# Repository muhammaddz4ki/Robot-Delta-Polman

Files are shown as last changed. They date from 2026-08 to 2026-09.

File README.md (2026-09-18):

# 3-DOF Parallel Delta Robot - Politeknik Manufaktur Bandung (POLMAN)








---

## Ringkasan Proyek (Abstract)

Repositori ini memuat rancang bangun dan implementasi terpadu sistem **3-DOF Parallel Delta Robot OS (v3.2)** yang dikembangkan di **Politeknik Manufaktur Bandung (POLMAN)**. Sistem ini mengintegrasikan kendali deterministik *low-level* berbasis mikrokontroler dengan ekosistem IoT nirkabel dan antarmuka web industri modern:

1. **Low-Level Motion Control (Arduino Mega 2560)**:
   - Perhitungan Kinematika Invers (*Inverse Kinematics*) berbasis model matematis Trossen Robotics.
   - Algoritma interpolasi koordinasi multi-axis (*Synchronized Multi-Axis Interpolation*) untuk lintasan 3D lurus dan mulus.
   - *Soft-Start Independent Power Homing* dengan peredam getaran beban inersia dan pengangkatan bertahap (*Smooth Staged Lift*).
   - Sistem keselamatan industri *Multi-Tier Emergency Stop (EMG)* dengan *Holding Torque* aktif dan proteksi hisap vakum.
   - Filter *software debounce* untuk sensor otomasi konveyor.
2. **IoT Gateway & Nirkabel (ESP32)**:
   - Mode ganda *Access Point (AP)* mandiri `DeltaRobot_Config` (`192.168.4.1`) dan *Station (STA)* Wi-Fi lokal.
   - Protokol mDNS lokal (`http://deltarobot.local`).
   - Jembatan komunikasi data *High-Speed UART (115200 baud)* dengan *CORS-enabled RESTful API JSON*.
   - Pembaruan program nirkabel *Over-The-Air (OTA) Web Firmware Update* (`/update`).
3. **Industrial Web Control Interface (React, Three.js, Node.js & MySQL)**:
   - Visualisasi *3D Digital Twin* interaktif dengan penanda target ruang kerja (*Ghost Target Markers*).
   - Penguji langkah per langkah (*Single-Step Sequencer*) untuk profiling Pick & Place yang aman.
   - Penyesuaian ketinggian instan (*Global Z-Offset Adjuster*).
   - Manajemen basis data resep / template koordinat kerja tanpa batas.
4. **Mechanical CAD 3D Models**:
   - Berkas CAD 3D presisi (.STEP & .STL) untuk lengan delta, bodi tripod, modul konveyor, dan beragam modul *end-effector* (vakum suction cup, servo gripper, soft gripper, dan laser).

---

## Arsitektur Sistem (System Architecture)

```mermaid
flowchart TD
    subgraph UserInterface["User Interface & Digital Twin Layer"]
        WebDashboard["React + Three.js Web Dashboard\n(3D Digital Twin, Step Sequencer, Jogging)"]
        DirectSerial["Serial Monitor / USB Terminal (115200 Baud)"]
    end

    subgraph ServerLayer["Application & Database Layer"]
        NodeServer["Node.js Express REST API\n(Port: 5000)"]
        MySQLDB[("MySQL Database\n(Users, Layouts, Recipes/Templates)")]
        NodeServer <--> MySQLDB
    end

    subgraph IoTGateway["IoT Gateway Layer (ESP32)"]
        ESP32Core["ESP32 Dual-Core SoC"]
        WiFiPortal["Dual Mode AP + STA Wi-Fi\n(mDNS: deltarobot.local)"]
        OTA["Web OTA Firmware Update (/update)"]
        RestBridge["REST API Bridge & CORS Handler"]
        ESP32Core --- WiFiPortal
        ESP32Core --- OTA
        ESP32Core --- RestBridge
    end

    subgraph EmbeddedController["Real-Time Motion & Safety Control (Arduino Mega 2560)"]
        MegaCore["ATmega2560 (16 MHz)"]
        IKEngine["Inverse Kinematics Engine\n(Trossen Robotics Model)"]
        HomingSync["Soft-Start Power Homing\n(3-Axis Zeroing Routine)"]
        SafetyManager["Emergency Stop (EMG)\n(Holding Torque & Vacuum Retention)"]
        EEPROMStore["EEPROM Memory Storage\n(Waypoints Backup)"]
        
        MegaCore --> IKEngine
        MegaCore --> HomingSync
        MegaCore --> SafetyManager
        MegaCore --> EEPROMStore
    end

    subgraph HardwareActuators["Mechanical & Actuator Layer"]
        MotorX["Stepper Motor X (Gear Ratio 3:1)"]
        MotorY["Stepper Motor Y (Gear Ratio 3:1)"]
        MotorZ["Stepper Motor Z (Gear Ratio 3:1)"]
        SuctionRelay["Relay Dinamo Vakum D12 (Active LOW)"]
        EmgSwitch["Saklar Darurat Fisik D31 (NC)"]
        LimitSwitches["Limit Switches (X, Y, Z Zeroing)"]
        ProximitySensors["Proximity Triggers (Debounced 30ms)"]
    end

    WebDashboard <-->|HTTP / REST API| NodeServer
    WebDashboard <-->|Direct Local REST / CORS| RestBridge
    NodeServer <-->|Serial / HTTP Bridge| ESP32Core
    DirectSerial <-->|UART0 (115200 Baud)| MegaCore
    RestBridge <-->|UART2 High-Speed (115200 Baud)| MegaCore

    IKEngine --> MotorX
    IKEngine --> MotorY
    IKEngine --> MotorZ
    MegaCore --> SuctionRelay
    EmgSwitch --> SafetyManager
    LimitSwitches --> HomingSync
    ProximitySensors --> MegaCore
```

---

## Parameter Kinematika & Ruang Kerja (Workspace Envelope)

Sistem mengadopsi formulasi matematis **3-DOF Parallel Delta Kinematics** dengan parameter dimensi terkalibrasi:

$$\begin{aligned}
\text{Radius Base } (f) &= 80.0\text{ mm} \\
\text{Panjang Lengan Biceps } (r_f) &= 130.0\text{ mm} \\
\text{Panjang Lengan Forearm } (r_e) &= 300.0\text{ mm} \\
\text{Radius End-Effector } (e) &= 40.0\text{ mm} \\
\text{Planetary Gear Ratio (Hanpose PG5.18)} &= 5.18:1 \\
\text{Sudut Arm saat Homing } (\theta_{\text{home}}) &= -36.0^\circ
\end{aligned}$$

### Amplop Ruang Kerja (Workspace Limits)
* **Batas Jangkauan Horizontal ($XY$):** Radius maksimal $150.0\text{ mm}$ ($\sqrt{X^2 + Y^2} \le 150.0\text{ mm}$).
* **Batas Jangkauan Vertikal ($Z$):** $Z_{\text{maks}} = -50.0\text{ mm}$ hingga $Z_{\text{min}} = -400.0\text{ mm}$ (Batas fisik absolut).
* **Margin Keselamatan Kerja ($Z_{\text{safe}}$):** $Z_{\text{safe\_min}} = -392.0\text{ mm}$ (Margin $8.0\text{ mm}$ dari $Z_{\text{min}}$ demi mencegah *stall* motor dan singularitas kinematika pada sudut lengan ekstrem).
* **Posisi Default Standby (Home):** $X = 0.0\text{ mm},\; Y = 0.0\text{ mm},\; Z = -200.0\text{ mm}$.

---

## Pemetaan Pin Perangkat Keras (Hardware Pinout)

### 1. Mikrokontroler Utama (Arduino Mega 2560)
| Kategori | Nama Sinyal | Pin Arduino Mega | Mode Pin | Keterangan / Konfigurasi |
|---|---|---|---|---|
| **Motor Stepper X** | STEP / DIR | Pin `7` / Pin `6` | OUTPUT | Hanpose PG5.18 (Ratio 5.18:1, 2.878 steps/deg) |
| **Motor Stepper Y** | STEP / DIR | Pin `44` / Pin `42` | OUTPUT | Hanpose PG5.18 (Ratio 5.18:1, 2.878 steps/deg) |
| **Motor Stepper Z** | STEP / DIR | Pin `5` / Pin `4` | OUTPUT | Hanpose PG5.18 (Ratio 5.18:1, 2.878 steps/deg) |
| **Relay Dinamo Vakum** | Suction Signal | Pin `12` | OUTPUT | Active LOW (LOW = ON, HIGH = OFF) |
| **Emergency Switch** | EMG Button | Pin `31` | INPUT_PULLUP | Active HIGH (NC Switch opens on press) |
| **Limit Switch X** | Limit Sensor | Pin `9` | INPUT_PULLUP | Active LOW saat tertekan |
| **Limit Switch Y** | Limit Sensor | Pin `11` | INPUT_PULLUP | Active LOW saat tertekan |
| **Limit Switch Z** | Limit Sensor | Pin `41` | INPUT_PULLUP | Active LOW saat tertekan |
| **Proximity Sensor 0** | Trigger RUN | Pin `2` | INPUT_PULLUP | Filter Debounce 30ms (Auto Run EEPROM) |
| **Proximity Sensor 1** | Trigger STARTA | Pin `53` | INPUT_PULLUP | Filter Debounce 30ms (Auto Profil A) |
| **Proximity Sensor 2** | Trigger STARTB | Pin `51` | INPUT_PULLUP | Filter Debounce 30ms (Auto Profil B) |
| **UART Bridge (ESP32)** | RX2 / TX2 | Pin `17` (RX2) / Pin `16` (TX2) | SERIAL2 | Kecepatan Tinggi: `115200 bps` |
| **USB Monitor (PC)** | USB CDC | Pin `0` (RX0) / Pin `1` (TX0) | SERIAL | Kecepatan: `115200 bps` |

### 2. IoT Gateway (ESP32 Dev Module)
| Antarmuka | Pin ESP32 | Terhubung Ke | Deskripsi |
|---|---|---|---|
| **UART2 RX** | GPIO `16` | Mega Pin `16` (TX2) | Menerima status koordinat & log Mega |
| **UART2 TX** | GPIO `17` | Mega Pin `17` (RX2) | Mengirim perintah gerak & kontrol ke Mega |

---

## Protokol Komunikasi & Serial Commands

Komunikasi data serial berjalan pada baudrate **`115200 bps`** dengan terminasi `Newline (\n)`.

| Perintah | Contoh Format | Deskripsi & Respons Sistem |
|---|---|---|
| **Gerak Koordinat** | `0 0 -250` | Menggerakkan end-effector ke target $(X, Y, Z)$ secara terkoordinasi |
| `HOME` | `HOME` | Menjalankan *Smooth Staged Homing* (Lifting $\rightarrow$ Centering $\rightarrow$ Zeroing) |
| `TIUP` / `AMBIL` | `TIUP` | Mengaktifkan pompa 1 untuk meniup (mencengkeram benda) dan menahan |
| `HISAP` / `LEPAS` | `HISAP` | Mengaktifkan pompa 2 untuk menghisap (melepaskan benda) |
| `SET_GRIP_TIME [t1] [t2]` | `SET_GRIP_TIME 4000 1000` | Mengatur durasi waktu tiup & hisap (1000 - 10000 ms / 1 - 10 detik) |
| `SET_GRIP_SPEED [p1] [p2]` | `SET_GRIP_SPEED 255 255` | Mengatur kecepatan PWM pompa 1 (Tiup) dan pompa 2 (Hisap) (0-255) |
| `STOP_PUMP` / `GRIP_STOP` | `STOP_PUMP` | Mematikan kedua pompa L298N (Kondisi Netral) |
| `EMG` / `STOP` | `EMG` | Toggle mode darurat (Motor mengunci posisi, pompa mati seketika demi keselamatan) |
| `RESET` | `RESET` | Melepas status darurat dan mengembalikan robot ke kondisi siap operasi |
| `STARTA` | `STARTA` | Menjalankan sekuensi otomatis *Pick & Place* Profil A |
| `STARTB` | `STARTB` | Menjalankan sekuensi otomatis *Pick & Place* Profil B |
| `SET_A_PICK X Y Z`| `SET_A_PICK 20 -30 -280` | Memperbarui titik ambil Profil A secara dinamis dari web |
| `SET_A_DROP X Y Z`| `SET_A_DROP 20 120 -320` | Memperbarui titik letak Profil A secara dinamis dari web |
| `SET_B_PICK X Y Z`| `SET_B_PICK -55 -40 -280` | Memperbarui titik ambil Profil B secara dinamis dari web |
| `SET_B_DROP X Y Z`| `SET_B_DROP -80 110 -320` | Memperbarui titik letak Profil B secara dinamis dari web |
| `SET_SPEED [val]` | `SET_SPEED 700` | Mengatur batas kecepatan maksimum motor stepper |
| `SET_ACCEL [val]` | `SET_ACCEL 350` | Mengatur akselerasi gerak motor stepper |
| `STATUS` | `STATUS` | Mengembalikan status koordinat aktual, status sensor, dan mode darurat |
| `SAVE` | `SAVE` | Menyimpan koordinat aktual ke EEPROM (Maksimal 10 titik) |
| `RUN` | `RUN` | Mengeksekusi pergerakan sekuensial seluruh waypoint di EEPROM |
| `CLEAR` | `CLEAR` | Menghapus seluruh memori titik koordinat di EEPROM |

---

## Antarmuka RESTful API (ESP32 & Node.js Backend)

### ESP32 Micro-Endpoints (Port `80` / `deltarobot.local`)
- `GET /` : Built-in Web Portal untuk pemindaian dan konfigurasi Wi-Fi.
- `GET /status` : Mengembalikan status koneksi Wi-Fi, IP, SSID, dan log UART terakhir.
- `GET /cmd?val=...` : Eksekusi perintah kontrol langsung via URL query.
- `POST /cmd` : Eksekusi perintah kontrol via JSON body (`{"command": "HOME"}`).
- `GET /scan` : Pemindaian daftar jaringan Wi-Fi 2.4 GHz di sekitar ESP32.
- `GET/POST /update` : Web portal untuk upload firmware nirkabel (*Over-The-Air*).

### Node.js Express Endpoints (Port `5000`)
- `POST /api/login` : Autentikasi operator / admin menggunakan JWT.
- `POST /api/command` : Dispatch perintah gerak ke hardware / simulator.
- `GET/POST /api/layout` : Manajemen konfigurasi tata letak visualizer 3D.
- `GET/POST/DELETE /api/templates` : Manajemen template resep koordinat Pick & Place di basis data MySQL.

---

## Struktur Direktori Proyek

```text
Robot-Delta/
├── .gitignore                   # Konfigurasi ignoransi berkas Git
├── package.json                 # Konfigurasi Unified Workspace Runner (1 Terminal)
├── README.md                    # Dokumentasi komprehensif proyek (Dokumen ini)
│
├── firmware/                    # Firmware Mikrokontroler (Standar Arduino IDE)
│   ├── DeltaRobot_Mega/
│   │   └── DeltaRobot_Mega.ino  # Firmware utama Arduino Mega 2560 (IK, Homing & Motion Control)
│   └── DeltaRobot_ESP32/
│       └── DeltaRobot_ESP32.ino # Firmware IoT Gateway ESP32 (Wi-Fi, REST API, OTA Update)
│
├── Backend/                     # Layanan Backend Node.js & Express
│   ├── .env.example             # Contoh konfigurasi environment backend
│   ├── package.json             # Dependensi backend (Express, MySQL2, JWT, CORS)
│   ├── server.js                # Entry point REST API Server
│   └── setup.sql                # Skema inisialisasi basis data MySQL
│
├── frontend/                    # Web Control Interface (React + Three.js + Vite)
│   ├── .env.example             # Contoh konfigurasi environment frontend
│   ├── package.json             # Dependensi frontend & UI libraries
│   ├── vite.config.js           # Konfigurasi bundler Vite
│   ├── index.html               # Entry point HTML
│   └── src/                     # Source code aplikasi React
│       ├── pages/               # Dashboard, Landing Page, Login, Visualizer
│       ├── components/          # 3D Canvas Twin, Coordinate Markers, Telemetry Cards
│       └── ...
│
├── hardware/                    # Desain CAD Mekanik & Manufaktur 3D
│   ├── Delta X 1 - v2.STEP       # Master assembly CAD model
│   ├── TripodBase.stl           # Base mounting tripod 3D model
│   ├── Conveyor-X/              # Desain modular konveyor pendukung
│   ├── Slider-X/                # Desain modular slider linear
│   ├── Delta-X-Robot/           # CAD komponen lengan dan bodi delta
│   └── Delta-X-End-Effectors/   # Beragam modul aktuator (Vacuum, Gripper, Soft, Laser)
│
└── docs/                        # Dokumentasi teknis terpusat
    └── ARCHITECTURE.md          # Spesifikasi arsitektur & pinout perangkat keras
```

---

## Panduan Instalasi & Pengoperasian

### 1. Pemrograman Firmware Mikrokontroler
1. **Arduino Mega 2560:**
   - Buka `firmware/DeltaRobot_Mega/DeltaRobot_Mega.ino` di **Arduino IDE**.
   - Pasang library: `AccelStepper` dan `EEPROM`.
   - Pilih Board: **Arduino Mega or Mega 2560** $\rightarrow$ Prosesor: **ATmega2560 (Mega 2560)**.
   - Sambungkan kabel USB dan klik **Upload**.
2. **ESP32 IoT Gateway:**
   - Buka `firmware/DeltaRobot_ESP32/DeltaRobot_ESP32.ino` di **Arduino IDE**.
   - Pilih Board: **ESP32 Dev Module** $\rightarrow$ klik **Upload**.
   - Hubungkan laptop ke Wi-Fi `DeltaRobot_Config` (Password: `12345678`), buka browser pada `http://192.168.4.1` atau `http://deltarobot.local` untuk konfigurasi jaringan.

### 2. Konfigurasi Web App (Backend + Frontend)

#### A. Persiapan Lingkungan & Dependensi
1. Pastikan service **MySQL** telah aktif (misal via XAMPP).
2. Di root folder `d:\Robot Delta`, install seluruh dependensi sekaligus dengan **satu perintah**:
   ```bash
   npm run install:all
   ```
   *(Perintah ini akan menginstal dependensi root runner, Backend Node.js, dan Frontend Vite secara otomatis).*

#### B. Menjalankan Sistem (Unified Runner - Cukup 1 Terminal)
Cukup buka **1 terminal** di root folder `d:\Robot Delta` dan jalankan:
```bash
npm run dev
```
> **Output Terminal:**
> * `[BACKEND]` (Biru)  : Node.js Express REST API aktif di `http://localhost:5000`
> * `[FRONTEND]` (Cyan) : Vite React Dashboard aktif di `http://localhost:5173`

Buka peramban pada **`http://localhost:5173`** untuk mengakses antarmuka kontrol.

#### C. Menjalankan Secara Manual (Opsi Terminal Terpisah)
Jika Anda ingin menjalankan layanan secara terpisah di terminal independen:
* **Hanya Backend**: `npm run dev:backend` (atau `cd Backend && npm run dev`)
* **Hanya Frontend**: `npm run dev:frontend` (atau `cd frontend && npm run dev`)
* **Build Produksi Frontend**: `npm run build`

---

## Pengembang & Pembimbing Akademik

* **Institusi:** Politeknik Manufaktur Bandung (POLMAN Bandung)
* **Program Studi:** Teknologi Rekayasa Informatika Industri
* **Pengembang Utama:** [Muhammad Dzaki](https://github.com/muhammaddz4ki)

---

## Lisensi (License)

Proyek ini didistribusikan di bawah lisensi terbuka untuk keperluan akademik, riset, dan pengembangan teknologi otomasi manufaktur.

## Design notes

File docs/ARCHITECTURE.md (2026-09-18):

# Arsitektur & Spesifikasi Sistem Delta Robot

Dokumen ini menjelaskan struktur arsitektur perangkat keras, firmware, antarmuka komunikasi, backend, dan frontend sistem kontrol Robot Delta Polman.

---

## 1. Ikhtisar Arsitektur Sistem

Sistem Robot Delta menggunakan arsitektur modular berlapis:

```mermaid
graph TD
    subgraph Pengguna & Operator
        Browser[Dashboard Web React + Three.js]
    end

    subgraph Server & Cloud
        Backend[Backend Node.js + Express]
        MySQL[(Database MySQL)]
    end

    subgraph Jaringan & Komunikasi
        WiFi[Koneksi Wi-Fi 2.4 GHz]
        USB[Web Serial API / USB COM]
    end

    subgraph Kontroler Mikrokontroler
        ESP32[ESP32 Wi-Fi & REST Gateway]
        Mega[Arduino Mega 2560 R3]
    end

    subgraph Aktuator & Sensor
        Steppers[3x Stepper NEMA 23 + Driver TB6600]
        Gripper[Vakum Solenoid / Relay Gripper]
        Proximity[3x Sensor Proximity Induktif]
    end

    Browser <-->|HTTP REST / WebSocket| Backend
    Backend <--> MySQL
    Browser <-->|HTTP REST /status, /cmd| ESP32
    Browser <-->|Direct Web Serial| Mega
    ESP32 <-->|UART Serial2 @ 115200 bps| Mega
    Mega --> Steppers
    Mega --> Gripper
    Mega <-- Proximity
```

---

## 2. Struktur Direktori Repositori

```text
Robot-Delta/
├── firmware/                      # Firmware mikrokontroler
│   ├── DeltaRobot_Mega/
│   │   └── DeltaRobot_Mega.ino    # Firmware kendali kinematika invers & stepper Mega 2560
│   └── DeltaRobot_ESP32/
│       └── DeltaRobot_ESP32.ino   # Firmware Wi-Fi Web Server & bridge UART ESP32
│
├── Backend/                       # Layanan REST API & database Node.js Express
│   ├── .env.example
│   ├── package.json
│   ├── server.js                  # Server utama (Port 5000)
│   └── setup.sql                  # Skema database MySQL
│
├── frontend/                      # Aplikasi antarmuka web (React + Vite + Three.js)
│   ├── public/                    # Model STL Robot & Logo SVG
│   ├── src/                       # Komponen UI, Visualisasi Digital Twin, Pages
│   ├── package.json
│   └── vite.config.js
│
├── hardware/                      # Desain mekanikal CAD & 3D Printing STL
│   ├── Conveyor-X/
│   ├── Delta-X-End-Effectors/
│   ├── Delta-X-Robot/
│   ├── Slider-X/
│   └── Delta X 1 - v2.STEP
│
├── docs/                          # Dokumentasi teknis terpusat
│   └── ARCHITECTURE.md
│
├── package.json                   # Root orchestrator runner (concurrently)
└── README.md                      # Dokumentasi umum proyek
```

---

## 3. Alokasi Pinout Perangkat Keras (Arduino Mega 2560)

| Komponen | Pin Arduino Mega | Keterangan |
| :--- | :--- | :--- |
| **Stepper Motor 1** | Pin 3 (STEP), Pin 4 (DIR) | Sumbu A (Lengan 1) |
| **Stepper Motor 2** | Pin 5 (STEP), Pin 6 (DIR) | Sumbu B (Lengan 2) |
| **Stepper Motor 3** | Pin 7 (STEP), Pin 8 (DIR) | Sumbu C (Lengan 3) |
| **Limit Switch / Home**| Pin 18, 19, 20 (Interrupt) | Switch Homing Sumbu 1, 2, 3 |
| **Sensor Proximity A** | Pin 53 | Deteksi benda kerja di Pick Point A |
| **Sensor Proximity B** | Pin 51 | Deteksi benda kerja di Pick Point B |
| **Sensor Proximity 3** | Pin 2 | Cadangan sensor proximity jalur conveyor |
| **Relay / Pompa Vakum**| Pin 12 | Aktuator Suction Cup (Grip & Release) |
| **Tombol Emergency** | Pin 21 (External Interrupt)| Interlock Darurat Perangkat Keras |
| **Komunikasi UART2** | Pin 16 (TX2), Pin 17 (RX2) | Terhubung ke ESP32 RX2/TX2 (115200 bps)|

---

## 4. Mode Operasi Standar Industri

Sistem mengadopsi standar keselamatan mesin industri:

1. **Mode MANUAL (Setup / Maintenance)**:
   - Pengguna bebas melakukan Jogging manual pada sumbu X, Y, dan Z.
   - Sensor proximity dinonaktifkan untuk mencegah pemicuan siklus otomatis tak terduga saat kalibrasi atau perawatan mekanik.
   - Akses penuh ke pengubahan parameter kecepatan, akselerasi, dan template koordinat.

2. **Mode AUTO (Line Production)**:
   - Tombol jogging dan konfigurasi dinonaktifkan demi keselamatan operator.
   - Sensor proximity membaca kedatangan part di konveyor secara aktif.
   - Robot secara otonom menjalankan siklus Pick & Place sesuai koordinat template yang tersimpan di EEPROM.

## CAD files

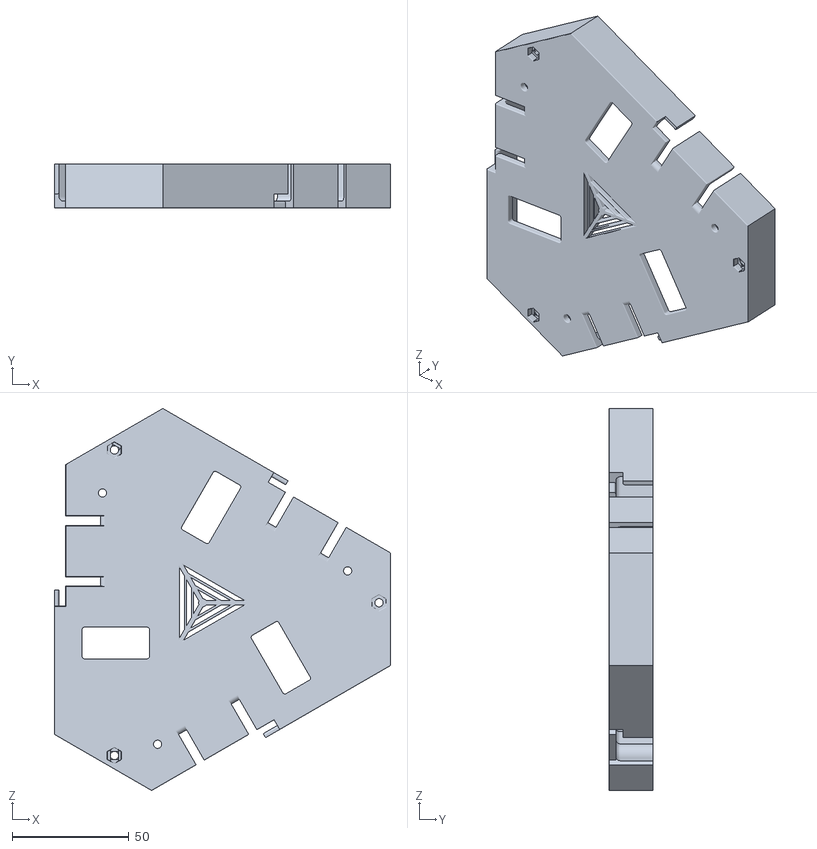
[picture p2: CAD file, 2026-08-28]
hardware/Delta-X-Robot/Delta X 1 - MainBox V2-1.STL
143.8 x 19.0 x 163.3

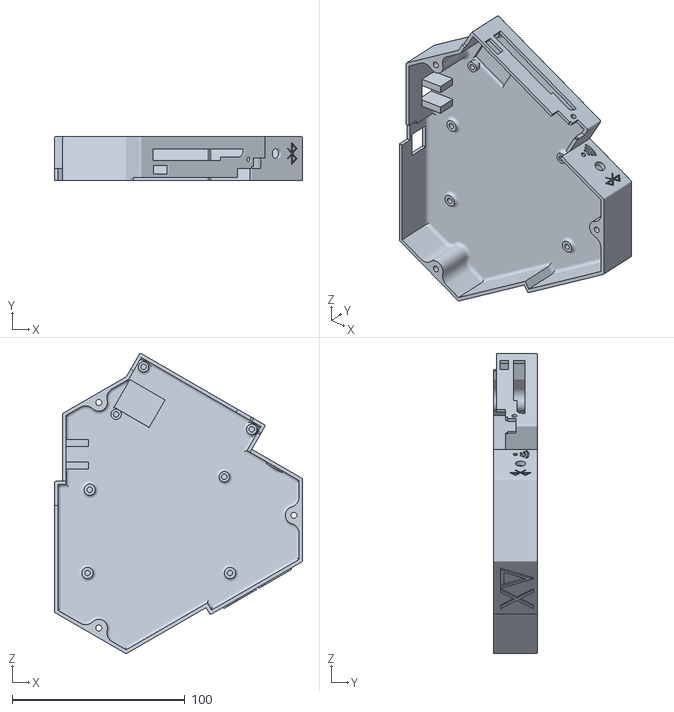
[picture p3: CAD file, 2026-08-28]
hardware/Delta-X-Robot/Delta X 1 - MainBoxLid V2-1.STL
143.8 x 25.8 x 173.8

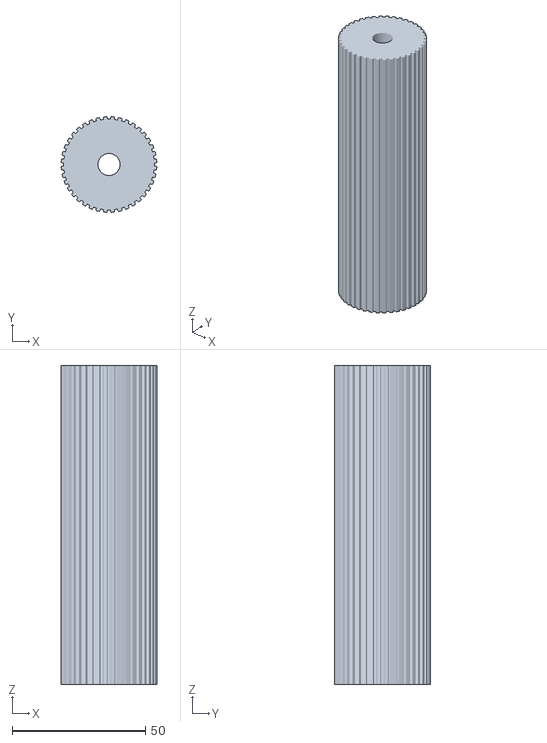
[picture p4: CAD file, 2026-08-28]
hardware/Conveyor-X/Roller.STL
36.0 x 36.0 x 119.8

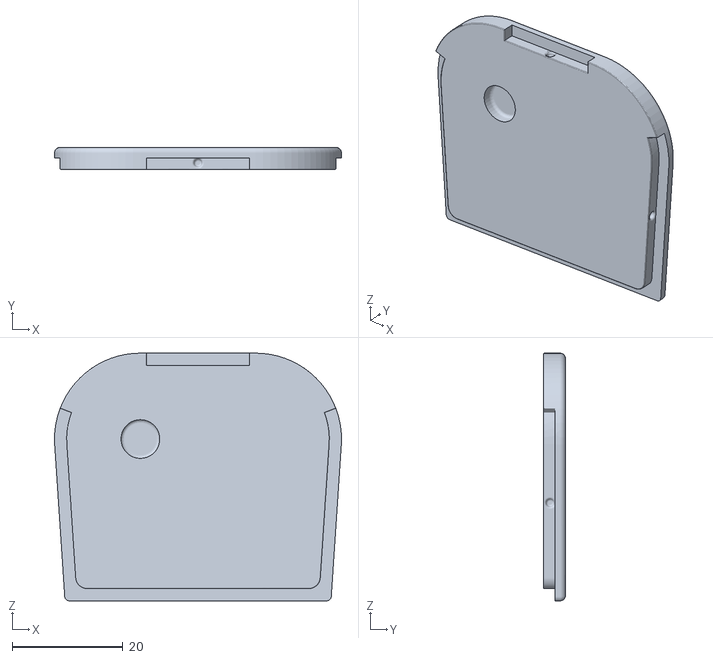
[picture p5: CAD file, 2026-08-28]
hardware/Delta-X-End-Effectors/Axis4 - Gripper/Axis4 Gripper Lib.STL
51.8 x 4.00 x 44.7

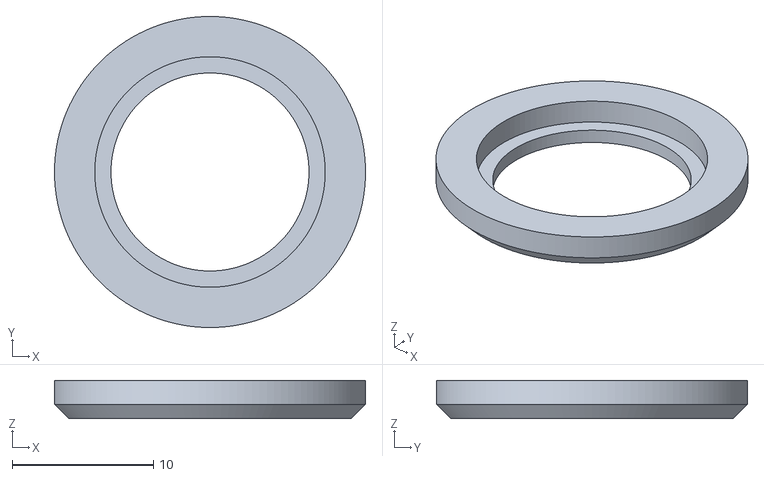
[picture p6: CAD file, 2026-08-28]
hardware/Delta-X-End-Effectors/Axis4 - Gripper/v2/Bearing.STL
22.0 x 22.0 x 2.70

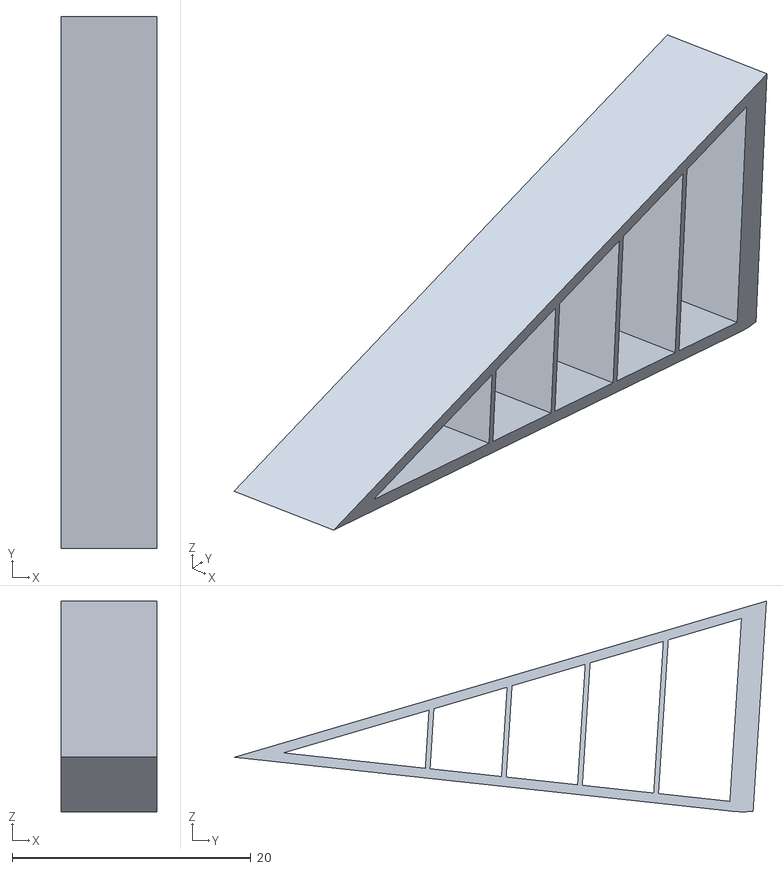
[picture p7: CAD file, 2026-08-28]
hardware/Delta-X-End-Effectors/Flexible Gripper/Flexible Gripper _ 2 _plastic.STL
8.00 x 44.5 x 17.7

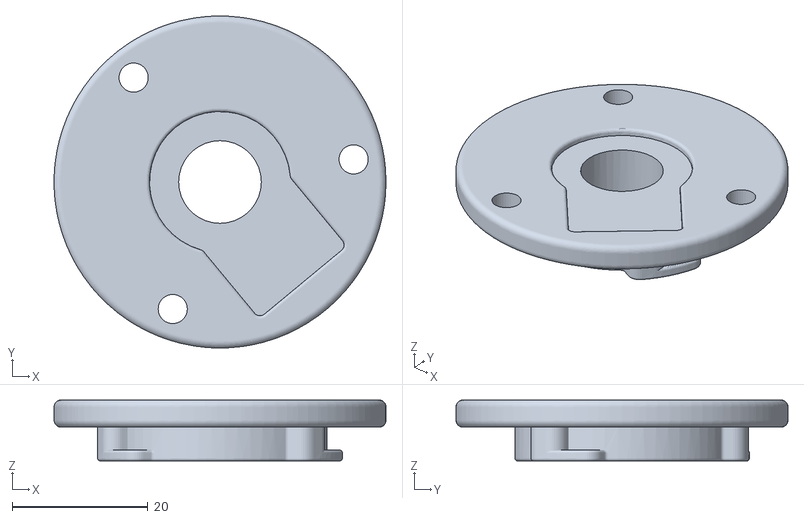
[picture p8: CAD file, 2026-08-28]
hardware/Delta-X-End-Effectors/v2/Step-file/Pen Holder 2.STL
49.0 x 49.0 x 9.00

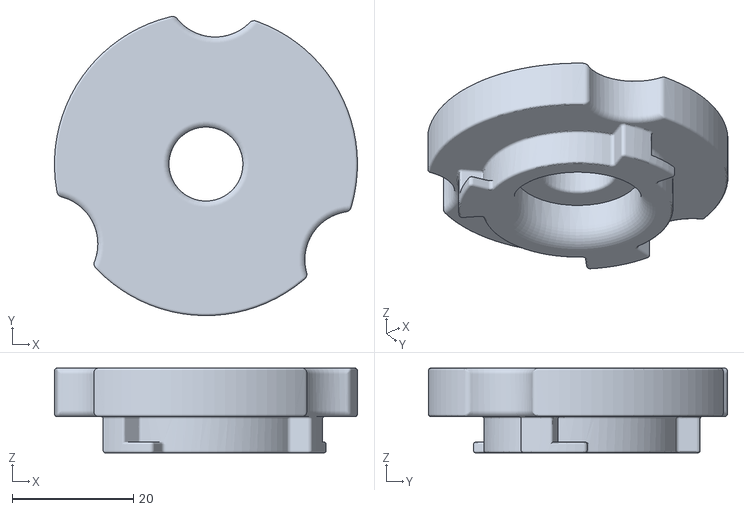
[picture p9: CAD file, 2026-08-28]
hardware/Delta-X-End-Effectors/Vacuum/Vaccum Jig.STL
50.0 x 49.4 x 14.0

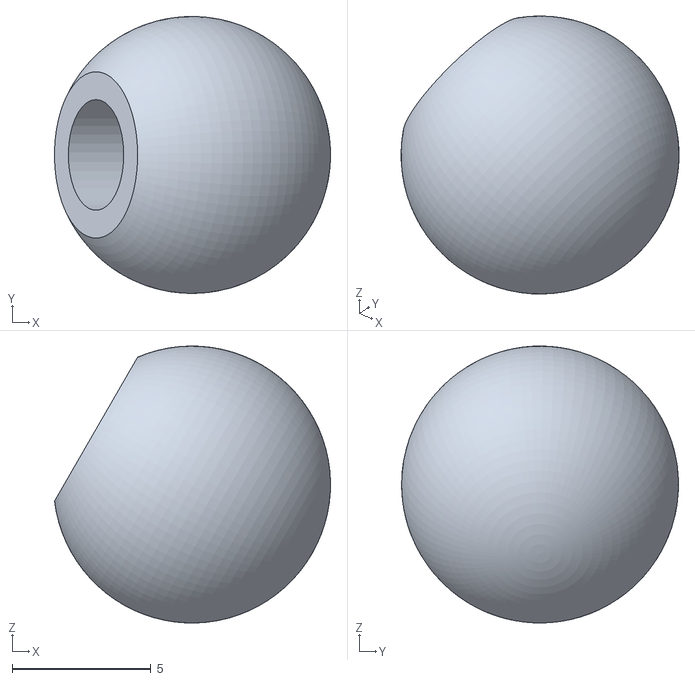
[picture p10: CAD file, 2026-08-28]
hardware/Delta-X-Robot/Delta X 1 - MovingBase-4 Joint Ball-4.STL
9.96 x 10.00 x 10.00

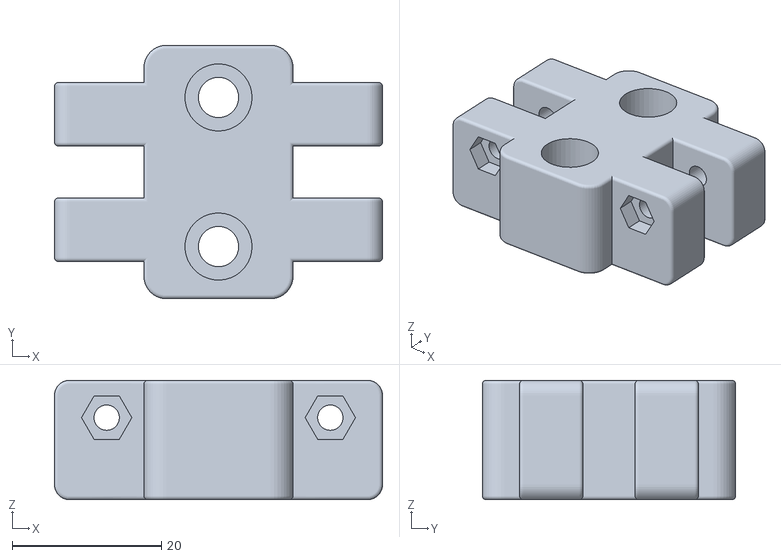
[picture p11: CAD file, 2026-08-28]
hardware/Slider-X/BeltKeeper.STL
44.0 x 34.0 x 16.0

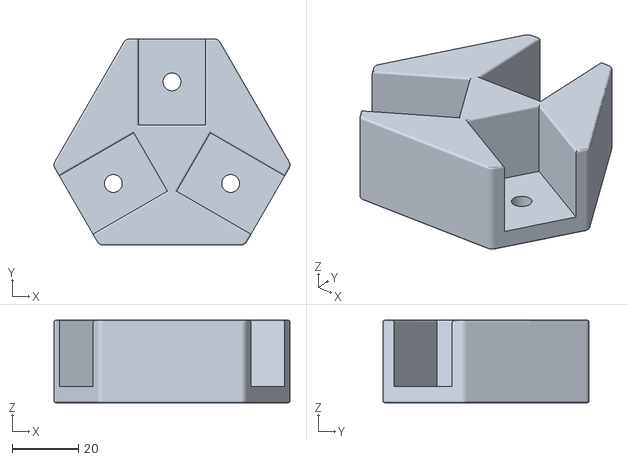
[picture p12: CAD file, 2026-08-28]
hardware/TripodBase.stl
71.4 x 62.4 x 25.0

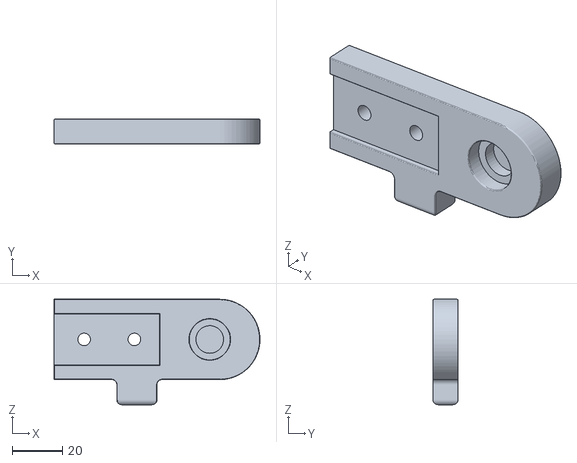
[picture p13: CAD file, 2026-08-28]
hardware/Conveyor-X/RollerAxisHolder.STL
82.0 x 10.0 x 42.0

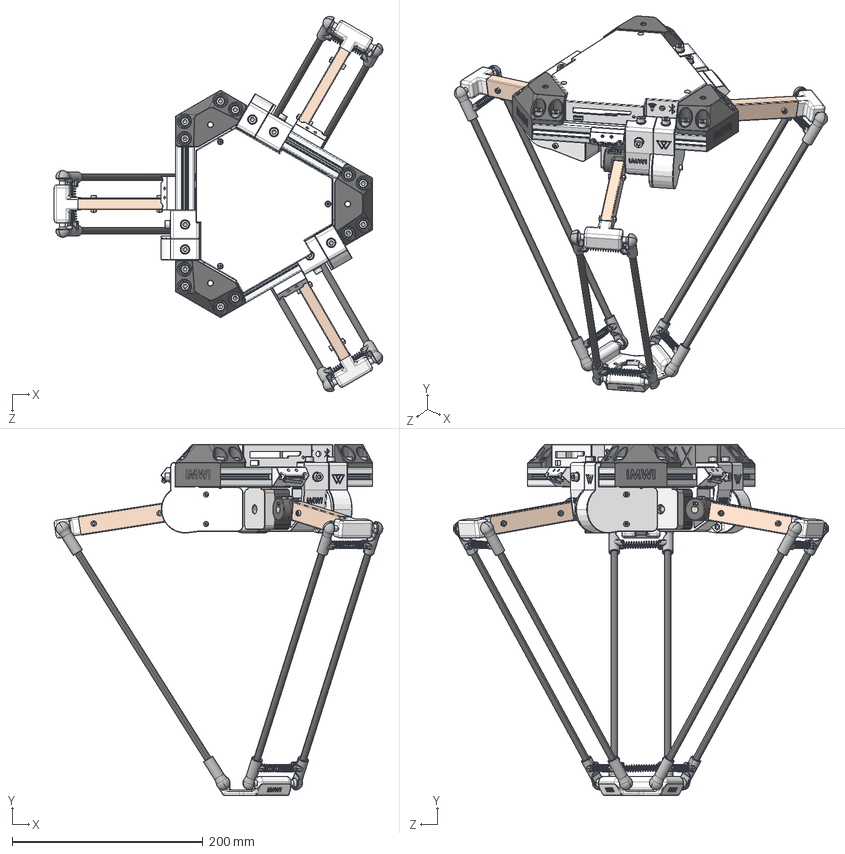
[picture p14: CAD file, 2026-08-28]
hardware/Delta X 1 - v2.STEP
345.0 x 368.5 x 394.1 mm
2020_Alu profile_Default<As Machined> x 3
Stepper Servo x 3
GearboxBody V2 x 3
Alu plate increase hardness x 3
Cross M3x10 bolt_Cross M3x10 bolt x 6
M3 Nut_M3 Nut x 21
Bearing 8_16 x 6
Bearing 5_16 x 3
BeltTensioner x 3
BeltTensioner2 x 3
BeltTensionerBase-v1 x 3
Cross M3x16 bolt_Cross M3x10 bolt x 3
M3x25 bolt_M3x8 bolt x 3
M3x12 bolt_M3x8 bolt x 3
M3x20 bolt_M3x8 bolt x 3
ring 8mm x 6
GearboxLid V2 x 3
M3x30 bolt_M3x8 bolt x 6
Frame connector x 3
M5 Washer_M5 Washer x 21
M5x10 bolt_M5x10 bolt x 21
T Slot Nut_______ _______ 6__ _5 x 21
inox8 x 3
Shoulder x 3
Nut m3 x 6
M3x8 bolt_M3x8 bolt x 6
Nhomtay_Default<As Machined> x 3
ElbowV2 x 3
M4x60 thread_M4x60 thread x 6
Joint Ball x 12
vongdem3m x 12
M3x15 bolt_M3x8 bolt x 6
MainBox V2
MainBoxLid V2
Endstop Limit Switch x 3
EndstopHolder x 3
M3x10 bolt_M3x8 bolt x 9
M3 T Slot Nut_______ _______ 6__ _5 x 6
GearBoxSprings x 3
GT2_60T_8 x 3
GT2_20T_5_____________1 x 3
Belt1-1^Delta X 1 x 3
M3x40 bolt_M3x8 bolt x 3
Base-EndEffecterV2
cacbon x 6
RodEnd-1-V2 x 12
Spring Stick x 12
ArmSpring x 6

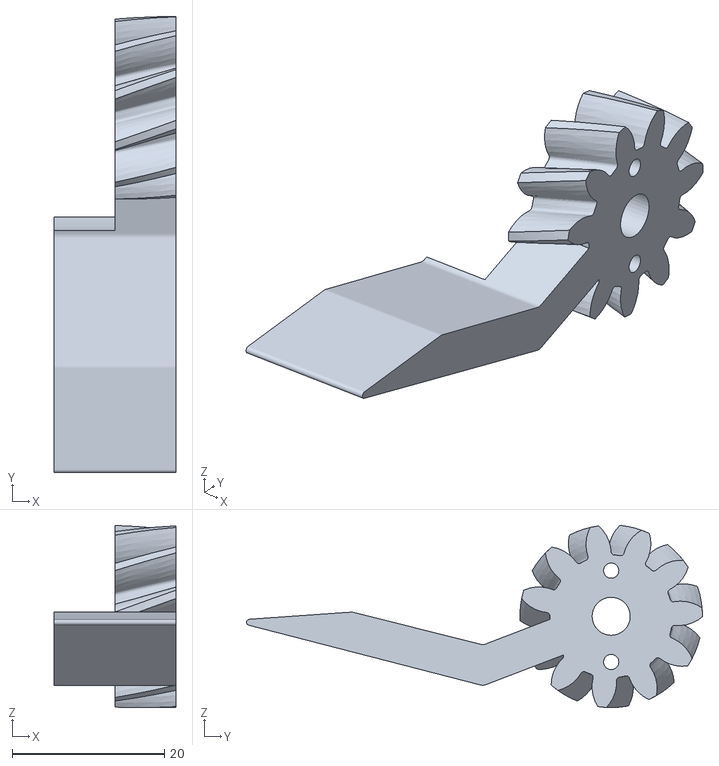
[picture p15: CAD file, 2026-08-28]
hardware/Delta-X-End-Effectors/Axis4 - Gripper/LH Helical gear 1.75M 11T.STL
16.0 x 59.9 x 23.9

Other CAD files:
hardware/Delta-X-End-Effectors/Axis4 - Gripper/v2/VaccumBase-SV.STL
hardware/Delta-X-End-Effectors/Flexible Gripper/Flexible Gripper Lib.STL
hardware/Delta-X-End-Effectors/v2/Step-file/SoftGripper.STEP
hardware/Delta-X-End-Effectors/Vacuum/LidVaccumBox.STL
hardware/Conveyor-X/Adjust-Tool.STL
hardware/Conveyor-X/ConveyorGearBox-Body.STL
hardware/Conveyor-X/ConveyorGearBox-Lid.STL
hardware/Conveyor-X/RollerAxisHolder-Mirror.STL
hardware/Conveyor-X/StepperWedge.STL
hardware/Delta-X-End-Effectors/Axis4 - Gripper/Axis4 Gripper Box.STL
hardware/Delta-X-End-Effectors/Axis4 - Gripper/Axis4 Gripper Top.STL
hardware/Delta-X-End-Effectors/Axis4 - Gripper/Axis4 Gripper.STEP
hardware/Delta-X-End-Effectors/Axis4 - Gripper/RH Helical gear 1.75M 11T.STL
hardware/Delta-X-End-Effectors/Axis4 - Gripper/v2/Axis4-Vacuum-Bottom-SV.stl
hardware/Delta-X-End-Effectors/Axis4 - Gripper/v2/Base-1.stl
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

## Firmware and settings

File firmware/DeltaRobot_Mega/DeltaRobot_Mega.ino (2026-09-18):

// =================================================================
// DELTA ROBOT v3.2 - POLMAN BANDUNG / MAJALENGKA (FULL INTEGRATION)
// HOMING = POWER MODE (manual, tanpa AccelStepper, independent timing per motor)
// Gerakan koordinat (XYZ, STARTA, STARTB, RUN) = AccelStepper Coordinated Move
// IK: standar Trossen Robotics + HOMING_THETA_DEG agar arah Y simetris
// END-EFFECTOR: SOFT ROBOTIC GRIPPER VIA DRIVER L298N (DUAL PUMP TIUP & HISAP)
// L298N PINOUT: IN1=23, IN2=25, IN3=27, IN4=29, ENA=45 (PWM), ENB=12 (PWM SERVOS)
// LOGIKA: TIUP = AMBIL BARANG | HISAP = LEPAS BARANG (DENGAN KONTROL WAKTU / TIMING)

#include <AccelStepper.h>
#include <EEPROM.h>

#define motorInterfaceType 1

// ===== PIN MOTOR =====
const int stepPinX = 7;  const int dirPinX = 6;
const int stepPinY = 44; const int dirPinY = 42;
const int stepPinZ = 5;  const int dirPinZ = 4;

// ===== PIN LIMIT SWITCH =====
const int limitX = 9;
const int limitY = 11;
const int limitZ = 41;

// ===== PIN PROXIMITY =====
const int proximityPin  = 2;
const int proximityPin1 = 53;
const int proximityPin2 = 51;
const int PROX_ACTIVE_STATE = HIGH;

// ===== PIN L298N DUAL PUMP CONTROLLER (SOFT GRIPPER) =====
// Pompa 1 = TIUP (Ambil Barang / Grip Inflate)
// Pompa 2 = HISAP (Lepas Barang / Release Deflate)
const int pump1_IN1 = 23; // Pompa 1 Arah A
const int pump1_IN2 = 25; // Pompa 1 Arah B
const int pump2_IN3 = 27; // Pompa 2 Arah A
const int pump2_IN4 = 29; // Pompa 2 Arah B
const int pump1_ENA = 45; // Speed Pompa 1 (PWM P45)
const int pump2_ENB = 12; // Speed Pompa 2 (PWM SERVOS D12)

// Parameter Soft Gripper
int pump1_Speed = 255; // PWM 0 - 255
int pump2_Speed = 255; // PWM 0 - 255
unsigned long gripTiupDuration   = 1200; // ms (Waktu tiup untuk ambil barang)
unsigned long gripHisapDuration  = 1000; // ms (Waktu hisap untuk lepas barang)
unsigned long gripExpandDuration = 800;  // ms (Waktu hisap sebentar untuk mengembang/membuka cakar sebelum ambil barang)
bool gripHoldContinuous = true;          // true = Tiup 100% penuh terus menerus selama membawa barang | false = Mode hemat daya 55%
String gripState = "NETRAL"; // "NETRAL", "TIUP", "HISAP"

const int emgPin   = 31;  // Emergency Switch Pin D31 (INPUT_PULLUP)
const int EMG_ACTIVE_STATE = HIGH; // Active HIGH saat tombol ditekan (NC switch)

bool isHardwareEmg = false;
bool isSoftwareEmg = false;

bool isEmgActive() {
  return isHardwareEmg || isSoftwareEmg;
}

void handleCommand(String input);

// ===== INDUSTRIAL OPERATION MODE (SAFETY INTERLOCK) =====
// MANUAL MODE: Sensor Proximity 100% diblokir & diabaikan. Operator leluasa Jogging, Kalibrasi, Setting.
// AUTO MODE  : Sensor Proximity aktif membaca conveyor. Tombol jogging & manual commands dikunci interlock.
bool isAutonomous = false; // false = MANUAL MODE (Default Aman) | true = AUTO MODE (Line Production)

// ===== PARAMETER DELTA (mm) - POLMAN BANDUNG =====
const float f  = 80.0;
const float e  = 40.0;
const float rf = 130.0;
const float re = 300.0;
const float baseHeight = 45.0;

// ===== PARAMETER MOTOR (HANPOSE 17HS4401S-PG5.18) =====
const float STEPS_PER_TURN   = 200.0; // 1.8 derajat per step
const float GEAR_RATIO       = 5.18;  // Planetary Gearbox Ratio 5.18:1
const float STEPS_PER_DEGREE = (STEPS_PER_TURN * GEAR_RATIO) / 360.0; // 2.877778 steps/derajat

// ===== INVERT ARAH MOTOR =====
const bool INVERT_X = false;
const bool INVERT_Y = true;
const bool INVERT_Z = false;

// ===== PARAMETER GERAKAN NORMAL (AccelStepper) =====
// Disetel ke kecepatan dan akselerasi bertorsi tinggi untuk motor Gearbox PG5.18
float baseMaxSpeed   = 800.0; // 800 steps/s (Torsi mantap, kuat mengangkat beban)
float baseAccel      = 400.0; // 400 steps/s² (Akselerasi halus, mencegah motor kehilangan langkah/stall)
const float MIN_SCALED_SPEED = 200.0;

// ===== PARAMETER HOMING - POWER MODE =====
const float HOMING_SPEED        = 130.0; // Torsi kuat, hening & presisi
const int   STEP_PULSE_WIDTH    = 8;
const unsigned long HOMING_TIMEOUT_MS = 30000UL;

const uint8_t HOMING_DIR_X = LOW;
const uint8_t HOMING_DIR_Y = LOW;
const uint8_t HOMING_DIR_Z = LOW;

// ===== SUDUT ARM SAAT HOMING =====
const float HOMING_THETA_DEG = -36.0;

// ===== WORKSPACE LIMITS (mm) =====
const float MIN_Z            = -400.0;
const float MAX_Z            = -50.0;
const float MAX_RADIUS       = 150.0;
const float Z_SAFETY_MARGIN  = 8.0;    // Margin keselamatan operasional (mm)
const float MIN_SAFE_Z       = MIN_Z + Z_SAFETY_MARGIN; // -392.0 mm (Batas operasional efektif aman)

// ===== POSISI DEFAULT SETELAH HOMING =====
const float DEFAULT_X = 0.0;
const float DEFAULT_Y = 0.0;
const float DEFAULT_Z = -200.0;

// ===== SETTING POSISI START_A (DINAMIS DARI WEB / BAWAAN POLMAN) =====
float seqA_pick_X = 30.0;
float seqA_pick_Y = -50.0;
float seqA_pick_Z_approach = -220.0;
float seqA_pick_Z_down     = -263.0;
float seqA_pick_Z_up       = -220.0;

float seqA_drop_X = 50.0;
float seqA_drop_Y = 140.0;
float seqA_drop_Z_approach = -220.0;
float seqA_drop_Z_down     = -310.0;
float seqA_drop_Z_up       = -220.0;

// ===== SETTING POSISI START_B (DINAMIS DARI WEB / BAWAAN POLMAN) =====
float seqB_pick_X = -50.0;
float seqB_pick_Y = -50.0;
float seqB_pick_Z_approach = -220.0;
float seqB_pick_Z_down     = -260.0;
float seqB_pick_Z_up       = -220.0;

float seqB_drop_X = -35.0;
float seqB_drop_Y = 130.0;
float seqB_drop_Z_approach = -220.0;
float seqB_drop_Z_down     = -310.0;
float seqB_drop_Z_up       = -220.0;

// ===== EEPROM =====
const byte EEPROM_MAGIC      = 0xA5;
const int  EEPROM_ADDR_MAGIC = 0;
const int  EEPROM_ADDR_COUNT = 1;
const int  EEPROM_ADDR_DATA  = 2;
const int  MAX_POINTS        = 10;
const int  POINT_SIZE        = sizeof(float) * 3;

// ===== STATE =====
bool homingComplete = false;
bool motorXStopped = false, motorYStopped = false, motorZStopped = false;

float currentAngle[3] = {0, 0, 0};
float currentX = 0, currentY = 0, currentZ = 0;

bool lastProxState   = false;
bool lastProx1State  = false;
bool lastProx2State  = false;
bool autoRunRunning  = false;

// ===== STEPPER (untuk gerakan koordinat saja) =====
AccelStepper stepperX(motorInterfaceType, stepPinX, dirPinX);
AccelStepper stepperY(motorInterfaceType, stepPinY, dirPinY);
AccelStepper stepperZ(motorInterfaceType, stepPinZ, dirPinZ);

// =================================================================
// LOG BRIDGE (OUTPUT KE USB SERIAL & ESP32 UART VIA SERIAL2)
// =================================================================
void sendResponse(String msg) {
  Serial.println(msg);
  Serial2.println(msg); // Pin 16 TX2 ke ESP32 RX
  Serial1.println(msg); // Fallback Pin 18 TX1
}

// =================================================================
// SOFT ROBOTIC GRIPPER HELPERS (DRIVER L298N)
// Logika: TIUP = Ambil Barang | HISAP = Lepas Barang | STOP = Netral
// =================================================================
void softGripStop() {
  digitalWrite(pump1_IN1, LOW);
  digitalWrite(pump1_IN2, LOW);
  analogWrite(pump1_ENA, 0);
  digitalWrite(pump1_ENA, LOW);

  digitalWrite(pump2_IN3, LOW);
  digitalWrite(pump2_IN4, LOW);
  analogWrite(pump2_ENB, 0);
  digitalWrite(pump2_ENB, LOW);

  gripState = "NETRAL";
  sendResponse(F("[GRIPPER] Pompa STOP / Netral (Driver L298N OFF Total 0V)"));
}

void softGripTiupRaw(bool active) {
  if (active) {
    // Matikan pompa hisap terlebih dahulu
    digitalWrite(pump2_IN3, LOW);
    digitalWrite(pump2_IN4, LOW);
    analogWrite(pump2_ENB, 0);

    // Nyalakan pompa 1 (Tiup / Ambil)
    digitalWrite(pump1_IN1, HIGH);
    digitalWrite(pump1_IN2, LOW);
    analogWrite(pump1_ENA, pump1_Speed);

    gripState = "TIUP";
    sendResponse(F("[GRIPPER] TIUP AKTIF -> Ambil Barang (Pompa 1 ON)"));
  } else {
    digitalWrite(pump1_IN1, LOW);
    digitalWrite(pump1_IN2, LOW);
    analogWrite(pump1_ENA, 0);
    gripState = "NETRAL";
    sendResponse(F("[GRIPPER] TIUP SELESAI -> Pompa 1 OFF"));
  }
}

void softGripHisapRaw(bool active) {
  if (active) {
    // Matikan pompa tiup terlebih dahulu
    digitalWrite(pump1_IN1, LOW);
    digitalWrite(pump1_IN2, LOW);
    analogWrite(pump1_ENA, 0);

    // Nyalakan pompa 2 (Hisap / Lepas)
    digitalWrite(pump2_IN3, HIGH);
    digitalWrite(pump2_IN4, LOW);
    analogWrite(pump2_ENB, pump2_Speed);

    gripState = "HISAP";
    sendResponse(F("[GRIPPER] HISAP AKTIF -> Lepas Barang (Pompa 2 ON)"));
  } else {
    digitalWrite(pump2_IN3, LOW);
    digitalWrite(pump2_IN4, LOW);
    analogWrite(pump2_ENB, 0);
    gripState = "NETRAL";
    sendResponse(F("[GRIPPER] HISAP SELESAI -> Pompa 2 OFF"));
  }
}

// Meniup selama durasi tertentu untuk mengambil barang dan TETAP MENAHAN
// Mendukung pre-expand: Mengembangkan cakar (HISAP sebentar) sebelum TIUP mengambil barang
bool softGripAmbilBarang(unsigned long durationMs = 0, bool preExpand = true) {
  // Jika diminta pre-expand dan gripper belum dalam mode HISAP, kembangkan cakar dulu
  if (preExpand && gripState != "HISAP") {
    sendResponse("[GRIPPER] Mengembangkan Cakar (HISAP " + String(gripExpandDuration) + " ms)...");
    softGripHisapRaw(true);
    if (!safeDelay(gripExpandDuration)) {
      if (!isEmgActive()) softGripStop();
      return false;
    }
  }

  unsigned long dur = (durationMs > 0) ? durationMs : gripTiupDuration;
  sendResponse("[GRIPPER] Memulai TIUP (Ambil Barang) selama " + String(dur) + " ms...");
  softGripTiupRaw(true);
  if (!safeDelay(dur)) {
    if (!isEmgActive()) softGripStop();
    return false;
  }
  // JANGAN softGripStop() di sini: Pompa Tiup TETAP ON menahan benda hingga titik drop!
  sendResponse(F("[GRIPPER] Barang Berhasil Dicengkeram -> TIUP TETAP ON MENAHAN BENDA!"));
  return true;
}

// Menangani tekanan holding selama robot membawa benda menuju Drop:
// Jika gripHoldContinuous == true: Tiup 100% PWM penuh terus menerus agar barang berat tidak jatuh/goyang
// Jika gripHoldContinuous == false: Mode hemat daya 55% PWM agar efisien dan arus motor tidak drop
void softGripHoldPressure() {
  if (gripState == "TIUP") {
    if (gripHoldContinuous) {
      analogWrite(pump1_ENA, pump1_Speed);
      sendResponse("[GRIPPER] Mode Tiup Aktif Penuh Terus (PWM " + String(pump1_Speed) + ") -> Benda Dicengkeram Kuat Penuh Selama Bergerak!");
    } else {
      int holdSpeed = (pump1_Speed * 55) / 100;
      if (holdSpeed < 80 && pump1_Speed >= 80) holdSpeed = 80;
      else if (holdSpeed < 40) holdSpeed = pump1_Speed;
      analogWrite(pump1_ENA, holdSpeed);
      sendResponse("[GRIPPER] Mode Hemat Daya Aktif (PWM " + String(holdSpeed) + ") -> Benda Menjepit Kuat & Torsi Motor 100% Penuh!");
    }
  }
}

// Menghisap selama durasi tertentu untuk melepas barang
bool softGripLepasBarang(unsigned long durationMs = 0) {
  unsigned long dur = (durationMs > 0) ? durationMs : gripHisapDuration;
  sendResponse("[GRIPPER] Memulai HISAP (Lepas Barang) selama " + String(dur) + " ms...");
  softGripHisapRaw(true);
  if (!safeDelay(dur)) { softGripStop(); return false; }
  softGripStop();
  sendResponse(F("[GRIPPER] Benda Berhasil Dilepas -> Pompa STOP / Netral"));
  return true;
}

// Fungsi alias legacy
void hisapOn()  { softGripAmbilBarang(); } // Ambil = Tiup
void hisapOff() { softGripLepasBarang(); } // Lepas = Hisap

void triggerEMG(bool fromSoftware = false) {
  if (fromSoftware) isSoftwareEmg = true;
  
  // Tahan posisi saat ini (Holding Torque aktif agar arm robot tidak melorot)
  stepperX.moveTo(stepperX.currentPosition());
  stepperY.moveTo(stepperY.currentPosition());
  stepperZ.moveTo(stepperZ.currentPosition());
  autoRunRunning = false;
  
  // PERMINTAAN USER: Saat EMG ditekan, pompa tiup/ambil barang TETAP ON menahan benda
  // agar benda yang sedang dicengkeram tidak jatuh/terlepas di tengah pergerakan!
  if (gripState == "TIUP") {
    sendResponse(F("[EMG] DARURAT AKTIF: Robot Berhenti di Tempat & Gripper Tetap Menahan Benda!"));
  } else {
    sendResponse(F("[EMG] DARURAT AKTIF: Robot Berhenti Seketika di Tempat!"));
  }
}

void releaseEMG() {
  isSoftwareEmg = false;
  isHardwareEmg = false;
  // PERMINTAAN USER: Saat EMG dilepas / ditekan lagi, matikan driver pompa total
  softGripStop();
  sendResponse(F("[EMG] Mode Darurat Dilepas: Driver Pompa OFF Total (0V) & Robot Otomatis Balik ke Home..."));
}

// =================================================================
// REAL-TIME EMG INTERRUPT CHECK & SAFE DELAY
// =================================================================
// Buffer Serial Non-Blocking agar loop stepper tidak terhambat timeout
String serialUsbBuf = "";
String serial2UartBuf = "";

void processSerialChar(char c, String &buf) {
  if (c == '\r') return;
  if (c == '\n') {
    buf.trim();
    if (buf.length() > 0) {
      if (autoRunRunning) {
        String up = buf; up.toUpperCase();
        if (up == "EMG" || up == "STOP" || up == "RESET" || up == "EMG OFF" || up == "EMG ON") {
          handleCommand(buf);
        }
      } else {
        handleCommand(buf);
      }
    }
    buf = "";
  } else {
    if (buf.length() < 120) {
      buf += c;
    }
  }
}

bool checkEmergencyInput() {
  // 1. Cek tombol fisik D31 dengan Software Debounce (40ms) agar kebal noise induksi motor/pompa
  static unsigned long lastEmgDebounceTime = 0;
  static bool lastRawEmg = false;
  static bool stableEmgState = false;

  bool rawEmg = (digitalRead(emgPin) == EMG_ACTIVE_STATE);
  if (rawEmg != lastRawEmg) {
    lastEmgDebounceTime = millis();
    lastRawEmg = rawEmg;
  }

  if ((millis() - lastEmgDebounceTime) >= 40) {
    if (rawEmg != stableEmgState) {
      stableEmgState = rawEmg;
      if (stableEmgState && !isHardwareEmg) {
        isHardwareEmg = true;
        triggerEMG(false);
      } else if (!stableEmgState && isHardwareEmg) {
        isHardwareEmg = false;
        releaseEMG();
        redoHoming();
      }
    }
  }

  // 2. Baca Serial USB PC secara NON-BLOCKING (tanpa delay/timeout)
  while (Serial.available() > 0) {
    char c = (char)Serial.read();
    processSerialChar(c, serialUsbBuf);
  }

  // 3. Baca Serial2 ESP32 Web secara NON-BLOCKING (tanpa delay/timeout)
  while (Serial2.available() > 0) {
    char c = (char)Serial2.read();
    processSerialChar(c, serial2UartBuf);
  }

  return isEmgActive();
}

bool safeDelay(unsigned long ms) {
  unsigned long start = millis();
  while (millis() - start < ms) {
    if (checkEmergencyInput()) return false;
    delay(1);
  }
  return true;
}

// =================================================================
// AccelStepper defaults & helpers
// =================================================================
void applyBaseStepperParams() {
  stepperX.setMaxSpeed(baseMaxSpeed); stepperX.setAcceleration(baseAccel);
  stepperY.setMaxSpeed(baseMaxSpeed); stepperY.setAcceleration(baseAccel);
  stepperZ.setMaxSpeed(baseMaxSpeed); stepperZ.setAcceleration(baseAccel);
  stepperX.setPinsInverted(INVERT_X, false, false);
  stepperY.setPinsInverted(INVERT_Y, false, false);
  stepperZ.setPinsInverted(INVERT_Z, false, false);
}

void stepPulse(int stepPin) {
  digitalWrite(stepPin, HIGH);
  delayMicroseconds(STEP_PULSE_WIDTH);
  digitalWrite(stepPin, LOW);
}

void allSteppersOff() {
  digitalWrite(stepPinX, LOW);
  digitalWrite(stepPinY, LOW);
  digitalWrite(stepPinZ, LOW);
}

// =================================================================
// INVERSE KINEMATICS - DELTA ROBOT (Trossen Robotics method)
// =================================================================
bool delta_calcAngleYZ(float x0, float y0, float z0, float &theta) {
  const float tan30 = 0.5773502692;
  float y1 = -0.5 * tan30 * f;
  y0 -= 0.5 * tan30 * e;

  float a = (x0*x0 + y0*y0 + z0*z0 + rf*rf - re*re - y1*y1) / (2.0*z0);
  float b = (y1 - y0) / z0;

  float d = -(a + b*y1)*(a + b*y1) + rf*(b*b*rf + rf);
  if (d < 0) return false;

  float yj = (y1 - a*b - sqrt(d)) / (b*b + 1);
  float zj = a + b*yj;

  theta = atan2(-zj, (y1 - yj)) * 180.0 / PI;
  return true;
}

bool calculateInverseKinematics(float x0, float y0, float z0, float theta[3]) {
  const float cos120 = -0.5;
  const float sin120 =  0.8660254038;

  if (!delta_calcAngleYZ(x0, y0, z0, theta[0])) return false;
  if (!delta_calcAngleYZ(x0*cos120 + y0*sin120,
                         y0*cos120 - x0*sin120,
                         z0, theta[1])) return false;
  if (!delta_calcAngleYZ(x0*cos120 - y0*sin120,
                         y0*cos120 + x0*sin120,
                         z0, theta[2])) return false;

  for (int i = 0; i < 3; i++) {
    if (theta[i] < -90.0 || theta[i] > 90.0) return false;
  }
  return true;
}

bool isInWorkspace(float x, float y, float z) {
  if (z > MAX_Z || z < MIN_Z) {
    sendResponse("[ERROR] Target Z (" + String(z, 1) + ") di luar batas fisik workspace (" + String(MIN_Z, 0) + " .. " + String(MAX_Z, 0) + " mm)");
    return false;
  }
  if (z < MIN_SAFE_Z) {
    sendResponse("[WARNING] Target Z (" + String(z, 1) + ") berada di zona batas mekanis kritis! (Batas aman: " + String(MIN_SAFE_Z, 1) + " mm)");
  }
  float radius = sqrt(x*x + y*y);
  if (radius > MAX_RADIUS) {
    sendResponse("[ERROR] Radius XY (" + String(radius, 1) + ") > batas " + String(MAX_RADIUS, 0) + " mm");
    return false;
  }
  return true;
}

// =================================================================
// [FIX3] DETEKSI ZONA EKSTREM / NEAR-SINGULARITY PADA WORKSPACE
// Mendeteksi jika titik berada di > 85% MAX_RADIUS agar gerakan adaptif
// =================================================================
bool isNearWorkspaceEdge(float x, float y) {
  float radius = sqrt(x*x + y*y);
  return (radius > MAX_RADIUS * 0.85);  // ambang 85% dari radius maksimum (127.5mm jika MAX_RADIUS = 150mm)
}

// =================================================================
// CETAK SUDUT LENGAN HASIL INVERSE KINEMATICS (POLMAN LOGIC)
// =================================================================
void printInverseKinematicsAngles(float theta[3]) {
  String ang = "[IK] Theta1=" + String(theta[0], 1) + "° | Theta2=" + String(theta[1], 1) + "° | Theta3=" + String(theta[2], 1) + "°";
  sendResponse(ang);
}
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
void loop() {
  // 1. Cek Serial USB Monitor & Emergency Switch D31
  checkEmergencyInput();

  // 2. Baca Sensor Proximity Otomasi dengan Software Debounce (30ms)
  // [FIX] Software debounce sejati berbasis millis(): reset timer jika sinyal mentah berubah,
  // dan hanya trigger otomasi setelah kondisi stabil > 30ms untuk eliminasi noise sensor induktif
  static unsigned long lastProxDebounceTime = 0;
  static bool lastRawProx  = false;
  static bool lastRawProx1 = false;
  static bool lastRawProx2 = false;
  static bool stableProx   = false;
  static bool stableProx1  = false;
  static bool stableProx2  = false;

  bool rawProx  = (digitalRead(proximityPin)  == PROX_ACTIVE_STATE);
  bool rawProx1 = (digitalRead(proximityPin1) == PROX_ACTIVE_STATE);
  bool rawProx2 = (digitalRead(proximityPin2) == PROX_ACTIVE_STATE);

  // [FIX] Setiap kali nilai mentah salah satu sensor berubah, reset timer debounce
  if (rawProx != lastRawProx || rawProx1 != lastRawProx1 || rawProx2 != lastRawProx2) {
    lastProxDebounceTime = millis();
    lastRawProx  = rawProx;
    lastRawProx1 = rawProx1;
    lastRawProx2 = rawProx2;
  }

  // [FIX] Jika pembacaan mentah telah stabil > 30ms, evaluasi dan trigger aksi pada transisi stabil
  if ((millis() - lastProxDebounceTime) >= 30) {
    if (isAutonomous && !isEmgActive() && !autoRunRunning) {
      if (rawProx1 && !stableProx1) {
        sendResponse(F("[PROXIMITY 1] Sensor A (Pin 53) terdeteksi -> START_A"));
        runAutoSequence();
      }
      else if (rawProx2 && !stableProx2) {
        sendResponse(F("[PROXIMITY 2] Sensor B (Pin 51) terdeteksi -> START_B"));
        runAutoSequence1();
      }
      else if (rawProx && !stableProx) {
        sendResponse(F("[PROXIMITY] Sensor (Pin 2) terdeteksi -> AUTO RUN"));
        runStoredCoordinates();
      }
    }

    // [FIX] Perbarui nilai stabil setelah deteksi transisi
    stableProx  = rawProx;
    stableProx1 = rawProx1;
    stableProx2 = rawProx2;
    lastProxState  = stableProx;
    lastProx1State = stableProx1;
    lastProx2State = stableProx2;
  }

  // 3. Eksekusi Langkah Stepper
  if (!isEmgActive()) {
    stepperX.run();
    stepperY.run();
    stepperZ.run();
  }
}

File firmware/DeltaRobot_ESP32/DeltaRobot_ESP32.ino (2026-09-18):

// =================================================================
// DELTA ROBOT - ESP32 IOT GATEWAY & WEB CONTROLLER
// FITUR: Dual Mode AP + STA Wi-Fi, REST API JSON, CORS Support,
//        mDNS (http://deltarobot.local), OTA Web Firmware Update,
//        High-Speed UART Bridge (115200 baud) ke Arduino Mega
// =================================================================

#include <WiFi.h>
#include <WebServer.h>
#include <Preferences.h>
#include <ESPmDNS.h>
#include <Update.h>

#define RXp2 16 // Hubungkan ke Pin 16 (TX2) Mega
#define TXp2 17 // Hubungkan ke Pin 17 (RX2) Mega

WebServer server(80);
Preferences prefs;

String currentSSID = "";
String currentPass = "";
String lastMegaLog = "Menunggu status robot...";

// Helper untuk mengirim CORS headers agar Web React tidak diblokir browser
void sendCORSHeaders() {
  server.sendHeader("Access-Control-Allow-Origin", "*");
  server.sendHeader("Access-Control-Allow-Methods", "GET, POST, OPTIONS");
  server.sendHeader("Access-Control-Allow-Headers", "Content-Type, Authorization, X-Requested-With");
}

void handleOptions() {
  sendCORSHeaders();
  server.send(204);
}

String escapeJsonString(String input) {
  String out = "";
  for (unsigned int i = 0; i < input.length(); i++) {
    char c = input.charAt(i);
    if (c == '"') out += "\\\"";
    else if (c == '\\') out += "\\\\";
    else if (c == '\r' || c == '\n') out += " ";
    else if (c >= 32 && c <= 126) out += c;
  }
  return out;
}

// Built-in Web Portal untuk konfigurasi Wi-Fi langsung di browser
void handleRoot() {
  sendCORSHeaders();
  bool isConnected = (WiFi.status() == WL_CONNECTED);
  String clientIp = isConnected ? WiFi.localIP().toString() : "Belum Terhubung";
  
  String html = "<!DOCTYPE html><html><head><meta charset='UTF-8'><meta name='viewport' content='width=device-width,initial-scale=1'>";
  html += "<title>Delta Robot Wi-Fi Portal</title><style>";
  html += "body{font-family:system-ui,-apple-system,sans-serif;background:#0d1117;color:#c9d1d9;margin:0;padding:20px;display:flex;justify-content:center;}";
  html += ".card{background:#161b22;border:1px solid #30363d;border-radius:12px;max-width:440px;width:100%;padding:24px;box-shadow:0 8px 24px rgba(0,0,0,0.5);}";
  html += "h2{color:#58a6ff;margin-top:0;font-size:1.3rem;display:flex;align-items:center;gap:8px;}";
  html += ".badge{padding:4px 8px;border-radius:20px;font-size:0.75rem;font-weight:bold;}";
  html += ".badge-ok{background:#238636;color:#fff;} .badge-warn{background:#d29922;color:#fff;}";
  html += "label{font-size:0.85rem;color:#8b949e;display:block;margin-top:14px;margin-bottom:4px;}";
  html += "input,select{width:100%;box-sizing:border-box;background:#0d1117;border:1px solid #30363d;color:#fff;padding:10px;border-radius:6px;font-size:0.9rem;}";
  html += "button{width:100%;margin-top:16px;background:#238636;color:#fff;border:none;padding:12px;border-radius:6px;font-size:0.95rem;font-weight:bold;cursor:pointer;transition:0.2s;}";
  html += "button:hover{background:#2ea043;}";
  html += ".scan-btn{background:#1f6feb;margin-top:8px;} .scan-btn:hover{background:#388bfd;}";
  html += ".info{background:#0d1117;border-left:3px solid #58a6ff;padding:10px;margin:14px 0;font-size:0.82rem;line-height:1.4;}";
  html += "</style></head><body><div class='card'>";
  html += "<h2>Delta Robot ESP32</h2>";
  html += "<div class='info'>";
  html += "<strong>Status Mode:</strong> " + String(isConnected ? "<span class='badge badge-ok'>TERHUBUNG</span>" : "<span class='badge badge-warn'>AP MANDIRI</span>") + "<br>";
  html += "<strong>Wi-Fi Tersimpan:</strong> " + (currentSSID.length() > 0 ? currentSSID : "<i>(Kosong)</i>") + "<br>";
  html += "<strong>IP Client:</strong> " + clientIp + "<br>";
  html += "<strong>IP Access Point:</strong> 192.168.4.1";
  html += "</div>";

  html += "<form method='POST' action='/setwifi'>";
  html += "<label>SSID / Nama Wi-Fi:</label>";
  html += "<input type='text' id='ssid' name='ssid' value='" + currentSSID + "' placeholder='Contoh: POCO F5 atau Wi-Fi Rumah' required>";
  html += "<label>Password Wi-Fi:</label>";
  html += "<input type='password' name='pass' placeholder='Masukkan password Wi-Fi'>";
  html += "<button type='submit'>Simpan ke ESP32 & Hubungkan</button>";
  html += "</form>";

  html += "<button class='scan-btn' onclick='scanWifi()'>Pindai Wi-Fi Sekitar</button>";
  html += "<div id='scanResults' style='margin-top:10px;'></div>";

  html += "<script>";
  html += "function scanWifi(){";
  html += "  const r = document.getElementById('scanResults');";
  html += "  r.innerHTML = '<small style=\"color:#8b949e\">Memindai...</small>';";
  html += "  fetch('/scan').then(res=>res.json()).then(data=>{";
  html += "    if(data.networks && data.networks.length>0){";
  html += "      let h = '<label>Pilih Wi-Fi Terdeteksi:</label><select onchange=\"document.getElementById(\\'ssid\\').value=this.value\">';";
  html += "      h += '<option value=\"\">-- Pilih Wi-Fi --</option>';";
  html += "      data.networks.forEach(n=>{ if(n.ssid) h += `<option value=\"${n.ssid}\">${n.ssid} (${n.rssi} dBm)</option>`; });";
  html += "      h += '</select>';";
  html += "      r.innerHTML = h;";
  html += "    } else { r.innerHTML = '<small style=\"color:#f85149\">Tidak ada Wi-Fi terdeteksi.</small>'; }";
  html += "  }).catch(e=>{ r.innerHTML = '<small style=\"color:#f85149\">Gagal memindai.</small>'; });";
  html += "}";
  html += "</script>";

  html += "</div></body></html>";
  server.send(200, "text/html", html);
}

// Mengembalikan status koneksi ESP32 dalam format JSON untuk React Dashboard
void handleStatus() {
  sendCORSHeaders();
  bool isConnected = (WiFi.status() == WL_CONNECTED);
  String mode = isConnected ? "connected" : "ap_mode";
  String ip = isConnected ? WiFi.localIP().toString() : WiFi.softAPIP().toString();
  String ssid = isConnected ? currentSSID : "DeltaRobot_Config";

  String json = "{";
  json += "\"status\":\"" + mode + "\",";
  json += "\"ip\":\"" + ip + "\",";
  json += "\"ssid\":\"" + ssid + "\",";
  json += "\"ap_ip\":\"" + WiFi.softAPIP().toString() + "\",";
  json += "\"mdns\":\"http://deltarobot.local\",";
  json += "\"last_log\":\"" + escapeJsonString(lastMegaLog) + "\"";
  json += "}";

  server.send(200, "application/json", json);
}

// Pindai jaringan Wi-Fi 2.4 GHz sekitar
void handleScan() {
  sendCORSHeaders();
  int n = WiFi.scanNetworks();
  String json = "{\"networks\":[";
  for (int i = 0; i < n; ++i) {
    if (i > 0) json += ",";
    String ssid = WiFi.SSID(i);
    ssid.replace("\"", "");
    json += "{\"ssid\":\"" + ssid + "\",\"rssi\":" + String(WiFi.RSSI(i)) + ",\"secure\":" + String(WiFi.encryptionType(i) != WIFI_AUTH_OPEN ? "true" : "false") + "}";
  }
  json += "]}";
  WiFi.scanDelete();
  server.send(200, "application/json", json);
}
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

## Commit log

2026-08-28 feat: release 3-DOF Delta Robot IoT system (Firmware, ESP32 Gateway, Node.js Backend, React Web Dashboard, and 3D CAD)
    [3D Printing head.STEP, Adjust-Tool.STL, Axis4 - Vacuum Bottom.STL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]
2026-08-28 docs: update comprehensive academic documentation, kinematics parameters, hardware pinout, and REST API specification
2026-09-01 fix(firmware): invert motor X direction (INVERT_X=true) for calibrated physical rotation
    [DeltaRobot_Mega.ino]
2026-09-01 feat(hardware): upgrade motor parameters for Hanpose 17HS4401S-PG5.18 planetary gearbox stepper (ratio 5.18:1)
2026-09-01 feat(web): update default speed (1000) and acceleration (500) for Hanpose PG5.18 planetary stepper
2026-09-01 feat(firmware): direct power homing enabled for Hanpose PG5.18 planetary stepper
2026-09-01 fix(firmware): implement absolute step tracking (moveTo) with round() to guarantee 100% position repeatability
    [DeltaRobot_Mega.ino]
2026-09-01 fix(firmware): calibrate native step ratio for Hanpose PG5.18, keep absolute position tracking, and fix relay start glitch
    [DeltaRobot_Mega.ino]
2026-09-01 fix(sequence): update START_A and START_B workflow to Pick -> Transit Home -> Drop -> Standby Home
    [DeltaRobot_Mega.ino]
2026-09-01 fix(sync): eliminate UART buffer collision on template load and standardize clean auto sequence trajectory
    [DeltaRobot_Mega.ino]
2026-09-01 fix(motion): add settling delays at waypoints, dynamic speed scaling, and serial isolation during auto sequence
    [DeltaRobot_Mega.ino]
2026-09-01 fix(sequence): implement exact Polman homing sequence (Pick -> Home to Limit Switch -> Drop -> Home to Limit Switch)
    [DeltaRobot_Mega.ino]
2026-09-01 fix(kinematics): transit through center standby (0, 0, -200) before and after homing to eliminate rod collision
    [DeltaRobot_Mega.ino]
2026-09-01 fix(sync): auto-sync profile coordinates before START A/B and update calibrated default points in firmware
    [DeltaRobot_Mega.ino]
2026-09-01 perf(motion): smooth coordinated trajectory for auto sequences eliminating mid-cycle homing shudder
2026-09-01 fix(sequence): restore limit-switch homing cycles for START A/B with smooth center transitions
    [DeltaRobot_Mega.ino]
2026-09-02 feat: enhance landing page specs & fix autonomous dual-sensor detection with NPN/PNP polarity support
    [DeltaRobot_Mega.ino]
2026-09-02 feat(sensor): add live pin transition logs and CEK SENSOR diagnostic tool for Auto Mode
2026-09-02 fix(sensor): restore exact working HIGH proximity detection logic
    [DeltaRobot_Mega.ino]
2026-09-02 feat(ui): implement fully responsive layout across mobile, tablet, laptop, and widescreen devices
2026-09-02 fix(landing): position 3D robot model below title and CTA button on mobile view
2026-09-18 feat: enhance industrial UI, fix mode switching race condition, and template persistence
    [TripodBase.stl]
2026-09-18 refactor: reorganize project structure to professional standards (firmware, hardware, docs)
    [3D Printing head.STEP, Adjust-Tool.STL, Axis4 - Vacuum Bottom.STL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]
